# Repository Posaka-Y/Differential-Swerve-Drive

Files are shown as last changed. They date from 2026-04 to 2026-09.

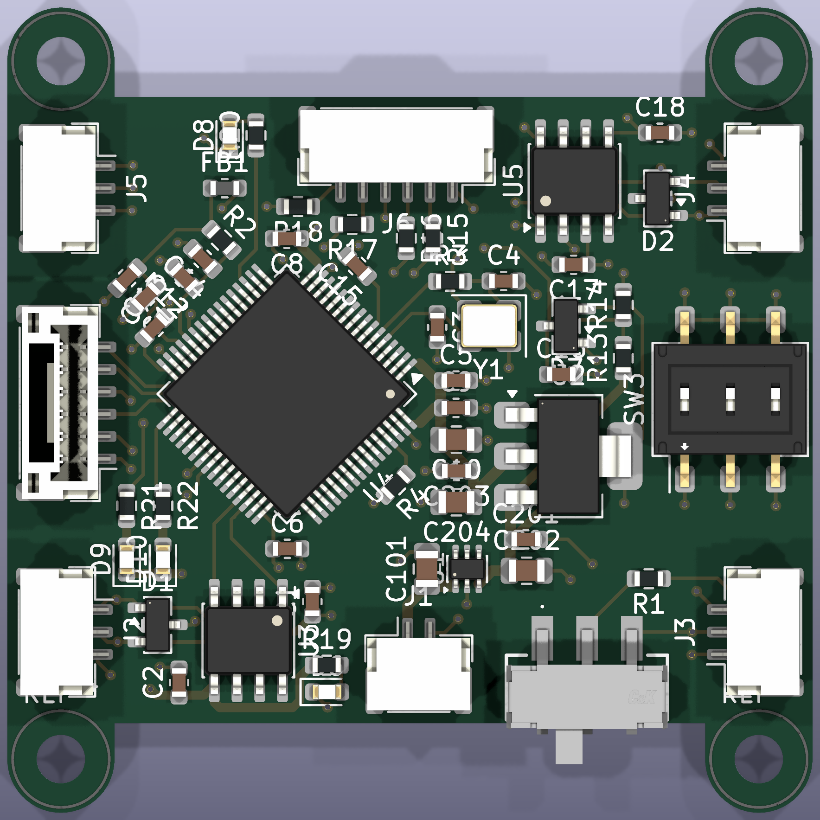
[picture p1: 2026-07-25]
.ai_board_top.png

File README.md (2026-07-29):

# Differential Swerve Drive

差動ステアユニット3基で構成する移動機構の、機構・制御・基板・ファームウェアをまとめた開発リポジトリです。

各ユニットはM3508+C620を2組とAMT222A-Vを持ち、ユニット内で差動の操舵・駆動制御を完結します。中央Teensy 4.1が3ユニットを協調制御し、mini PCはUSB-CDC経由でGUI・ログ・キャリブレーション操作を担います。

## 現在の構成

```text
mini PC (GUI / log)
  | USB-CDC
Teensy 4.1 (中央制御・安全I/O)
  |-- CAN1: 差動ステアユニット x3
  |     `-- STM32G474RET6 + C620 x2 + M3508 x2 + AMT222A-V
  |
  `-- CAN3: オドメトリ/IMUノード (unitId=4)
        `-- STM32F405RGT6 + AMT102 x3 + ICM-42688-P
```

- 中央CANとユニット内C620 CANは、いずれもClassic CAN 1 Mbpsの別バス。
- 制御系は中央の24V→5V降圧から`COMM_A / COMM_B / +5V / GND`で分配し、各基板で3.3Vを生成する。
- 確定事項の唯一の正本は[docs/ARCHITECTURE_DECISIONS.md](docs/ARCHITECTURE_DECISIONS.md)。

## まず読むもの

| 目的 | 文書 |
|---|---|
| 文書全体の案内 | [docs/PROJECT_DOCUMENT_INDEX.md](docs/PROJECT_DOCUMENT_INDEX.md) |
| 現在地・次の作業 | [PROGRESS.md](PROGRESS.md) |
| 設計上の確定事項 | [docs/ARCHITECTURE_DECISIONS.md](docs/ARCHITECTURE_DECISIONS.md) |
| 全体構成と責務 | [docs/SYSTEM_ARCHITECTURE.md](docs/SYSTEM_ARCHITECTURE.md) |
| ユニット基板・中央基板・オドメトリ基板 | [docs/electrical/](docs/electrical/) |
| 制御・運動学 | [docs/control/](docs/control/) |
| CAN・ネット名・メッセージ | [docs/communication/COMMUNICATION_NAMING_AND_IDS.md](docs/communication/COMMUNICATION_NAMING_AND_IDS.md) |
| ファームウェア | [firmware/README.md](firmware/README.md) と [firmware/PROGRESS.md](firmware/PROGRESS.md) |
| KiCad基板設計 | [hardware/README.md](hardware/README.md) |

階層化済みの`docs/control/`、`docs/electrical/`、`docs/communication/`などが更新対象です。`docs/`直下の旧メモは履歴として保存しており、更新対象ではありません。

## よく使うコマンド

リポジトリルートで実行します。

```powershell
# STM32G474 ファームウェア
.\firmware\scripts\build.ps1
.\firmware\scripts\flash.ps1

# KiCad設計のERC・PDF・DRC確認
.\tools\kicad\check.ps1
```

ファームウェア用ツールチェーンはスクリプトが自動検出します。パスに日本語を含むため、ビルド系スクリプトでは絶対パスを`cmd.exe`経由で渡さず、相対パスを使います。

## リポジトリ構成

```text
docs/       設計仕様、設計判断、試験計画
firmware/   STM32G474向けファームウェアとベンチ検証記録
hardware/   KiCadプロジェクト、共通ライブラリ、参照回路
tools/      KiCad検証などの補助スクリプト
```

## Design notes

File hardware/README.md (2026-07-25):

# hardware

KiCadによる基板設計。共通ブロック方針は `docs/electrical/CARRIER_BOARD_BUILD_PLAN.md` 冒頭を参照。

## 構成

```text
hardware/
  lib/             共通シンボル・フットプリントライブラリ
  blocks/          共通階層シート(can_interface, power_input_5v, status_led, mcu_min_g474)
  unit-board/      差動ステアユニット基板(STM32G474RET6)
  central-board/   中央制御ボード(Teensy 4.1)
  odometry-board/  オドメトリ基板(STM32F405RGT6 + AMT102 A/B相 x3)
  reference/       流用元プロジェクト(下表)
```

## 流用元(reference/)

| 参照 | 形式 | 流用するブロック | ライセンス |
|---|---|---|---|
| `candleLightFD/` ([linux-automation/candleLightFD](https://github.com/linux-automation/candleLightFD)) | **KiCadソース**(階層シート: MCU / PSU / transceiver) | CANトランシーバ周り(TJA1051T/3 + 100nF + 120Ω)→ `TCAN1051VDRQ1`に置換して `blocks/can_interface` の下敷きにする。階層シートの切り方・リリースフォルダ構成(製造データの出し方)も運用の手本になる | CERN-OHL v1.2(流用時はライセンス表記を維持) |
| `mks-canable-v2.0-schematic.pdf` ([makerbase-mks/CANable-MKS](https://github.com/makerbase-mks/CANable-MKS)) | PDF回路図 | STM32G431のMCU最小構成(電源、BOOT0、水晶、SWD)。G474RET6版を起こすときの照合用 | 回路図公開(リポジトリ記載に従う) |
| `nucleo-g474re-mb1367-c05-schematic.pdf`(ST MB1367)**※未取得** | PDF回路図 | **G474RET6そのものの最小構成の正解例**(VDD/VDDA処理、NRST、BOOT0、HSE周り)。ピンごとのデカップリング数の確認はこれを正とする | ST評価ボード回路図(参照用) |
| `ARK_CANNODE/` ([ARK-Electronics/ARK_CANNODE](https://github.com/ARK-Electronics/ARK_CANNODE)) | PDF回路図 + BOM(`Hardware/Rev 1/`) | 逆接保護(LM66100)、CANコネクタ2個並列のデイジーチェーン渡り、外部信号のESDダイオード、TJA1051+FET切替終端(参考のみ)。詳細は`CARRIER_BOARD_REQUIREMENTS.md`「回路図作成メモ」 | リポジトリのLICENSE参照 |
| `datasheets/` | データシートPDF | AMT22 rev1.10(コネクタピン順1=+5V/2=SCLK/3=MOSI/4=GND/5=MISO/6=CS)、PESD1CAN rev04(1/2=ライン、3=GND) | メーカー資料(参照用) |

※ MB1367回路図はst.comが自動取得を弾くため手動ダウンロードが必要:
<https://www.st.com/resource/en/schematic_pack/mb1367-g474re-c05_schematic.pdf>(または c04)。取得したらこのフォルダに上記ファイル名で保存する。

## 設計ルール

- 回路図のネット名は `docs/communication/COMMUNICATION_NAMING_AND_IDS.md` の命名に従う(`COMM_A/B`、`C620_CAN_*`、`PWR_*`、`_N`)。
- ピン割当は `docs/electrical/CARRIER_BOARD_REQUIREMENTS.md`(ユニット)/ `ODOMETRY_BOARD_REQUIREMENTS.md`(オドメトリ)の表が正本。
- シンボル・フットプリントは`lib/`に置き、KiCad標準ライブラリ依存を減らす(後続プロジェクトへの持ち出しやすさ優先)。
- プロジェクト固有ライブラリの収録範囲と標準ライブラリ割当は`lib/LIBRARY_MANIFEST.md`を正本とする。標準部品を無理由に複製しない。
- 発注前チェックは `docs/checklists/REVIEW_CHECKLIST.md`。

## CLI検証

KiCad 10で保存した回路図・PCBは、リポジトリルートから次で検証する。

```powershell
.\tools\kicad\check.ps1
```

既定では `hardware/unit-board/unit-board` を対象にERC、回路図PDF出力、DRCを実行し、結果を
`$env:TEMP\differential-swerve-kicad-check` へ保存する。CI相当の厳格な確認では
`-FailOnViolations`を付け、ERC/DRC違反があれば終了コードを非0にする。

PCB未着手の段階で回路図だけを厳格確認する場合は、空PCBのDRCを省く。

```powershell
.\tools\kicad\check.ps1 -FailOnViolations -SkipDrc
```

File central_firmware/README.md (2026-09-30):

# Teensy central-control firmware

`central_firmware`はTeensy 4.1中央制御のハードウェア非依存コアから実装を始める。
現段階ではCAN/USB/安全I/Oドライバを含まず、`control/swerve_coordinator`と
`control/steer_trajectory`が次を担当する。

- 車体twistとtwist微分から3ユニットのsteer角、wheel rpm、FFを同一時刻断面で算出
- 低速時だけの中央flip判断と連続unwrap角
- 停止特異点で直前steer角を保持
- 3ユニットの最悪要求に合わせたplanned motor-rpm包絡の共通scale
- 新指令後のSTATUS3 Low→Highを要求する3輪`MOTION_SETTLED`集約
- rate/accel/decel/jerk制約とjerk過渡込み停止距離を持つunwrapped steer軌道

駆動ユニットは半径0.250mの円上へ120deg等配する。車体`+X前・+Y左`でunit 1/3間の辺を
`+Y`側(センサーモジュール搭載側)に置き、unit 1=`(-216.5,+125)mm`、
unit 2=`(0,-250)mm`、unit 3=`(+216.5,+125)mm`とする。
公称車輪径は65mmなので、`default_coordinator_config()`は半径0.0325mと上記座標を設定する。
接地変形や製造差を実走距離から校正した場合は、各`wheel_radius_m`を実効半径で上書きできる。
半径が0以下のユニットを含む設定は指令生成を拒否し、全出力を0に保つ。

ホスト試験:

```bash
central_firmware/scripts/test-host.sh
```

次段階は、正本の機体寸法を設定したうえでTeensy 4.1のFlexCAN_T4アダプタ、200Hz
twist/steer profiler、通常STOP/ESTOP状態機械をこのコアの外側へ接続する。空走P4では
jerk=100k/200kを評価したが応答優先ではjerk=0が最速だったため、production configの
non-zero jerk採用値は接地3輪試験後に確定する。

## 再アーム判定コア（2026-09-26）

control/arm_controllerを追加。GUI ARMイベントとSW211押下を同じ安全判定へ入力し、ARMによるコイル許可とRUNによる運転許可を分離する。詳細はdocs/software/MINIPC_GUI_AND_TEENSY.md。

アダプタは毎周期ArmInputsを構築する。初期値は安全側（未許可）。GPIOにmotor_power_enableを反映し、motion_permitted=falseでは車輪出力をゼロにする。boot_sessionは起動/GUI再接続ごとに新しい値を供給し、再接続時はコントローラを再初期化する。USB受信イベントをキューへ保持せず、期限切れリンク/指令をlinks_ok=falseへ反映する。run_eventはC620立上がりや運転の他条件を確認したイベントだけを渡す。

これは判定コアの実装であり、Teensy GPIO/USB、本体ディスプレーGUIとの接続は未実装。今回ビルド・テスト・書き込みは実施していない。

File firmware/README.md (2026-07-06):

# NUCLEO-G474RE firmware

STM32G474RET6 向けの GCC/CMake ベアメタルプロジェクトです。NUCLEO-G474RE の B1 USER (PC13、アクティブHigh) を押している間、LD2 (PA5) が点灯します。入力は20 msデバウンスされます。

## 必要なツール

- STM32Cube for Visual Studio Code 拡張
- Arm GNU Toolchain (`arm-none-eabi-gcc`) — `winget install Arm.GnuArmEmbeddedToolchain`
- CMake 3.22 以降
- Ninja
- 書き込み時のみ STM32CubeProgrammer

CMake / Ninja / STM32CubeProgrammer / ST-LINK GDB Server は STM32Cube 拡張が
`%LOCALAPPDATA%\stm32cube\bundles` に導入済みのものを使う。手動で PATH に
追加する必要はない。`scripts/toolchain.ps1` が build/flash 実行時に自動で
発見して PATH へ載せる(優先順: 既存 PATH → 拡張バンドル → Arm GNU Toolchain
既定インストール先)。

VS Code のデバッグ構成 (`.vscode/launch.json`) はバンドル内の
`arm-none-eabi-gdb` / `ST-LINK_gdbserver` / `STM32_Programmer_CLI` を
絶対パスで参照している。拡張がバンドルを更新してバージョンディレクトリが
変わった場合はパスを追従させること。

## CLI

リポジトリのルートから実行します。

```powershell
.\firmware\scripts\build.ps1
.\firmware\scripts\build.ps1 -Configuration Release
.\firmware\scripts\flash.ps1
```

POSIX 環境では `firmware/scripts/build.sh` と `flash.sh` を使えます。生成物は `firmware/build/debug` または `firmware/build/release` に配置されます。

## 構成

- `src/main.c`: アプリケーションのエントリポイント
- `src/platform/`: STM32 固有の startup、clock、GPIO
- `include/app_config.h`: アプリ共通設定
- `linker/`: メモリマップ
- `cmake/`: GCC クロスコンパイル設定
- `scripts/`: 再現可能なビルド・書き込みコマンド

新機能は原則として `src/` と `include/` の対応するモジュールへ追加し、MCU レジスタへの直接アクセスは `platform/` 内に限定します。

自作基板へ移行するときは、最初に `src/platform/gpio.c` のLED・ボタンのポート、ピン番号、入力極性を基板回路に合わせて変更します。

実機書き込みで詰まりやすい点、接続モード、エンコーダの配線・段階テスト、自作基板のSWD要件は [docs/BOARD_BRINGUP.md](docs/BOARD_BRINGUP.md) にまとめています。

現在の完了項目、実機状態、次の作業は [PROGRESS.md](PROGRESS.md) を参照してください。

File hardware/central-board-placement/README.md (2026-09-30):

> **作業先訂正 2026-09-29:** 現行は `hardware/central-board/central-board/central-board.kicad_pro`。22:45保存版へ移行済みで、クランプD405も `safety-1.kicad_sch` に反映済み。ERC0件。下記のcentral-board-placement対象/既存CAN4件という記載は以前の作業履歴。

> **2026-09-29クランプ更新:** X401→D405 AOS SMBJ33CA、SMB footprint割当済み。コイル両端並列、未割当9件。ERCは既存CAN4件。サージ/解放時間の実測・X402帰路結合は残件。

> **最新 2026-09-29：電源・CAN以外の配線を反映。** S02B/S04/S05、GPIO4pin×4組、Teensy用途ラベル。ERC193→4（残りCAN電源4件）。S04のヒューズ/クランプ/帰路結合/正式コネクタはTBD。157参照番号。以下の旧未配線・部品数記載は履歴。詳細は [配線記録](../../docs/electrical/CENTRAL_NONPOWER_WIRING_2026-09-29.md)。開いているKiCadは古い画面を保存せず再読込。

> **E-stop 2026-09-26更新:** U401 LTV-817S 1ch、J401は4pin（型番未確定）。ボタン別/予備監視16部品を削除。現在158実部品。前回ERCは変更前の記録。

# 中央基板 — 階層回路図・部品配置からの設計開始

> **2026-09-29更新:** J210の使用端子40本は用途global label、予約8本はNCで区別。新規global label30個、再アーム誤記READ_SW_N→REARM_SW_Nを訂正。C212/GNDだけ表示干渉を避けて移動し、同名3V3で接続。全48padのネット対応と既存ネット分断なしを検証。ERC217→194件（未配線等が残る）。最新人間向けPDFは`output/pdf/CENTRAL_BOARD_REV1_SCHEMATIC_2026-09-29.pdf`。KiCadで開いている場合は再読込してから編集を続ける。

> **2026-09-26現在: ユーザーがS02A電源回路の手配線を開始。** 以下の未配線/部品数/ERC一覧は初期配置時点の履歴。生成器で原本を再生成しない。電源回路は修正・再確認済み。最新記録は`output/kicad-check/central-power-fix-2026-09-26/REVIEW.md`を参照。現在174実部品、電源シートERC0件、全体383件。既にエディタで開いている場合は古い画面を保存せず再読込すること。

2026-09-23のユーザー指定に基づく、手配線用の新規プロジェクト。
トップシートを目次とし、機能別の子シートへシンボルを配置する。
**電源回路は配線・修正済み。他回路は未配線。製造用の完成回路図ではない。**

## 開き方

このフォルダの `central-board-placement.kicad_pro` をKiCadで開き、回路図エディタから
トップシート内の各階層シートを開く。
以後の手編集はこの新規プロジェクトで行う。
既存の `../central-board/central-board/` は別の作業データであり、今回置換しない。

トップ＋7子シート、178部品（LTV-847Sの4ユニットを含め181シンボル）。

| 子シート | 用紙 | 部品数 |
|---|---|---:|
| 5V入力・eFuse・USB diode-OR | A2 | 32 |
| 5V分配・Teensy・表示 | A2 | 38 |
| CAN1 センサ | A3 | 10 |
| CAN2 拡張 | A3 | 11 |
| CAN3 駆動 | A3 | 10 |
| E-stop監視・中央コイルdriver | A2 | 33 |
| Matek監視端子・外部I/O | A2 | 44 |

## 作業の境界

- 部品配置のみ。配線、ネットラベル、階層信号ピン、電源シンボル、NC指定は未作成。
- RefDesと部品値を付け、機能ごとの配線用余白を設ける。
- 未確定の部品値・型番・footprintはTBD/REVIEW等で明示する。
- 多ユニット部品は同一RefDesの各unitとして配置する。
- 未接続に関するERC結果はこの段階では意図された状態。ERC合格や製造可能とは扱わない。
- PCB配置・配線は含まない。

## 仕様参照

優先する資料:

1. `docs/ARCHITECTURE_DECISIONS.md`
2. `docs/electrical/PCB_BATCH_V2_CENTRAL_PLAN.md`
3. `docs/electrical/CENTRAL_BOARD_REV1_PDF_CHANGELOG_2026-09-23.md`
4. `docs/electrical/CENTRAL_BOARD_REV1_KICAD_ENTRY_REFERENCE.md`

2026-09-23版のCAN端子・中央コイルdriver・Teensy一体ソケットを基準とし、
旧資料の別体driver、基板内Buck、主接点専用監視回路を復活させない。
専用CANはGH3、汎用拡張CANだけは既存GH4の区別を保つ。
未確定箇所は接続・footprint・購入型番を確定してからPCBへ進める。

### 旧資料を参照するときの注意

- `reference-2026-09-12/modules-native/POWER_A_B1.kicad_sch` の旧eFuseシンボルは
  TPS259470LRPWRのpin番号が正本と異なるため流用しない。
  正番号はEN/UVLO=1、OVLO=2、AUXOFF=3、FLT=4、IN=5、OUT=6、
  dVdt=7、GND=8、ILM=9、ITIMER=10。
- Teensyのpad4は`MOTOR_PWR_EN`に使用する。旧転記表末尾のNC列挙より
  正式な48pin対応表を優先する。配置時点ではNCシンボル自体を置かない。
- Teensyの一体48pad footprintは2個の24pinシンボルへ重複して割り当てない。

## 再生成について

`tools/kicad/generate-central-placement.py` と部品一覧JSONは初期配置の生成元。
**手配線を始めた後は再生成で上書きしないこと。**
必要な変更はKiCad上で行うか、別出力先へ生成して比較する。

## 初期配置の確認結果

### 2026-09-26仕様差分の反映

- Teensy J210の右列表示順を48→25へ訂正（左列1→24、USB側を上）。ライブラリと回路図内cache、生成器を同期。全48pinの番号/信号名対応とソケットfootprintは保持。USB END表示を追加。PDFのTeensy図は元からこの順序。

- 同日追加指定で駆動Unit 1〜3の給電枝TP211〜TP213を削除。LEDで給電状態を見て、必要時はJ201〜J203で電圧を実測する。最新ERCは未接続493/入力未駆動13/電源未駆動15。

- USB側U102 `TPS259470ARPWR`、R107〜R112、C106〜C108、TP106を追加。外部5V優先のOVLO分圧、約1A制限、既存D102保持経路は転記表3.1に従う。
- GPIO電源列選択JP505を追加。1=3V3、2=VCC_GPIO_EXT（J507-1）、3=5V_EXP。ショートピン1個、出荷時1-2。IO/TVSは3.3Vのまま。
- J210のpad11/pin9はUSB fault入力候補と注記（提案）。pad36はNC。接続は手配線時に作成する。
- 既存全素子の座標/向き/UUIDを保持し、電源シートをA2へ拡張して下側へ追加した。元ファイルは`output/kicad-check/central-placement-2026-09-26/before/`へ退避。
- U101 `TPS259470LRPWR` / U102 `TPS259470ARPWR` のRPW footprintは未割当。ユーザーがPart Loaderで取得予定。JP505はKiCad標準1x3ヘッダfootprintを使用し、購入型番は未確定。
- 手配線用回路図: `output/pdf/CENTRAL_BOARD_REV1_SCHEMATIC_2026-09-26.pdf`（15ページ、14=USB eFuse、15=GPIO電源選択）。9月23日版は履歴として保持。
- ERCは未接続496、入力未駆動13、電源未駆動15のみ。配線前の状態であり製造用のERC合格ではない。

以下は2026-09-23初期配置時点の結果。最新版の検査は上記9月26日記録を参照。

KiCad 10のSVG/netlist出力成功。部品一覧との全件照合、Ref/unit重複なし、
主要ICのpin番号、割当footprintの実在、配線/ラベル/NCなしを検査した。
8ページを画像化して重なり・ページ外はみ出しを目視確認済み。
ERCは意図的な未接続464件・未駆動24件で、off-grid/library mismatchはない。
検査記録は `output/kicad-check/central-placement/`。

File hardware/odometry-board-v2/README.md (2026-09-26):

# V2 作業用プロジェクト

2026-09-23着手。**設計途中・製造禁止**。

要件正本: [UNIT_ODOMETRY_V2_REQUIREMENTS.md](../../docs/electrical/UNIT_ODOMETRY_V2_REQUIREMENTS.md)

V1の保存済み作業ツリーから分離した。ファイル名を維持しているのはKiCad階層インスタンス参照のため。
V1の製造済み基板との差分は基準マニフェストを参照。

2026-09-23: 回路図の旧GH6デバッグ端子J8を駆動V2と同じCortex Debug 1.27mm 2×5配列へ変更。1=MCUデジタル3.3VのVTref、2=SWDIO、3/5/9=GND、4=SWCLK、6=SWO、7/8=NC、10=NRST。UARTは独立した2.54mm 1×3スルーホールヘッダJ9（1=GND、2=MCU TX、3=MCU RX）へ変更。3.3Vロジック専用で給電ピンはない。ERC 0、変更箇所以外のネット接続比較を確認済み。詳細は`../../output/kicad-check/v2/odometry/swd-10pin-check.md`と`uart-header-check.md`。

J8の正式MPN・嵌合ケーブル・フットプリントは未確定で、回路図のFootprintは意図的に空欄。V2 PCBは旧GH6のまま、UART J9も未反映で、回路図との同期前に製造してはいけない。

ODOMのU3/U7/U9電源unit Cだけ回路図へ反映済み。ERC 0、XML netlistで6電源pinを確認。PCBの当該6padは未更新なので、回路図からPCBを更新し、電源配線と100nFを確認すること。

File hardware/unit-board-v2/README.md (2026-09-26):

# V2 作業用プロジェクト

2026-09-23着手。**設計途中・製造禁止**。

要件正本: [UNIT_ODOMETRY_V2_REQUIREMENTS.md](../../docs/electrical/UNIT_ODOMETRY_V2_REQUIREMENTS.md)

V1の保存済み作業ツリーから分離した。ファイル名を維持しているのはKiCad階層インスタンス参照のため。
V1の製造済み基板との差分は基準マニフェストを参照。

2026-09-23: 駆動回路図の旧GH6デバッグ端子J7をCortex Debug 1.27mm 2×5配列へ置換。pin1=MCUデジタル3.3V(VTref)、2=SWDIO、3/5/9=GND、4=SWCLK、6=SWO、7/8=NC、10=NRST。UARTは独立した2.54mm 1×3スルーホールヘッダJ9（1=GND、2=MCU TX、3=MCU RX）へ変更。3.3Vロジック専用で給電ピンはない。ERC 0、既存接続照合を確認済み。レポートは`../../output/kicad-check/v2/unit/uart-header-check.md`。

J7の正式MPN・キー形状・嵌合ケーブル・フットプリントは未確定で、回路図のFootprintは意図的に空欄。PCBはV1の旧GH6配置・配線が残るため、回路図との同期前に製造してはいけない。UART J9もPCBへ未反映。

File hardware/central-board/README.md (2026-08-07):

# Central board schematic

## Files

- `central-board.sch`: 責務別child sheetを並べたroot index。
- `modules/100-power.sch`: 5V入力、eFuse、star distribution。
- `modules/200-teensy.sch`: Teensy 4.1 socket、固定pin map、安全出力のdefault state。
- `modules/300-can.sch`: Sensor / Expansion / DriveのCAN 3系統。
- `modules/600-safety.sch`: 24V E-stop loop、contactor driver、絶縁監視、motor bus sense。
- `modules/700-monitoring.sch`: INA238と外付けKelvin shunt interface。
- `modules/800-expansion.sch`: I2C/UART/SPI/GPIO、rearm、test access。
- `../../tools/kicad/generate-central-board-modules.ps1`: root＋6 moduleの再生成script。
- `../../tools/kicad/generate-central-board-schematic.ps1`: module生成の入力になる詳細回路generator。通常は直接実行しない。
- `../../docs/electrical/CENTRAL_BOARD_SCHEMATIC_WITH_BOM.html`: オドメトリ／駆動module資料と同じA3横テンプレートのreview正本。
- `../../output/pdf/CENTRAL_BOARD_SCHEMATIC_WITH_BOM.pdf`: 1機能1ページの回路図＋注意点＋簡易BOM、全7ページ。

## 開き方

KiCad Schematic Editorから`central-board.sch`を直接開き、rootのsheet blockから担当moduleへ移動する。初回保存時にKiCadの現行`.kicad_sch`形式へ変換してよい。変換後は生成scriptによる上書きを止め、`.kicad_sch`と変換されたchild sheetsを正本へ切り替える。

## 現段階の使い方

人間reviewでは`CENTRAL_BOARD_SCHEMATIC_WITH_BOM.pdf`を先に使い、1機能ずつ信号の流れ、注意点、BOMを確認する。KiCad sheetはその結果を転記してERCするための下位資料であり、review PDFの代用にはしない。TPS259470、TCAN1051、INA238、LTV-847Sなどの正式pinはdatasheetとKiCad symbolの両方で最終照合する。

PCBへ進む前に次を行う。

1. generic symbolを正式なlibrary symbolへ置換し、pin typeとfootprintをdatasheetに対して照合する。
2. 図中`TBD`をすべて閉じる。特にeFuse UVLO/OVLO、24V input保護、contactor clamp、shunt sense source fuse。
3. `docs/electrical/CENTRAL_BOARD_SCHEMATIC_REFERENCE.md`の接続表とcross-checkする。
4. No Connect、PWR_FLAG、power pin typeを整理し、ERC 0件へ収束させる。

現時点のKiCad ERCはgeneric pin-explicit symbolとlegacy `.sch` labelのためacceptance判定に使用しない。PDF/netlist出力が可能なことまでは確認済みで、PCB開始条件は`.kicad_sch`化後のERC 0件である。

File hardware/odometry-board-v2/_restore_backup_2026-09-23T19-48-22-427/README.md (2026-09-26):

# V2 作業用プロジェクト

2026-09-23着手。**設計途中・製造禁止**。

要件正本: [UNIT_ODOMETRY_V2_REQUIREMENTS.md](../../docs/electrical/UNIT_ODOMETRY_V2_REQUIREMENTS.md)

V1の保存済み作業ツリーから分離した。ファイル名を維持しているのはKiCad階層インスタンス参照のため。
V1の製造済み基板との差分は基準マニフェストを参照。

2026-09-23: 回路図の旧GH6デバッグ端子J8を駆動V2と同じCortex Debug 1.27mm 2×5配列へ変更。1=MCUデジタル3.3VのVTref、2=SWDIO、3/5/9=GND、4=SWCLK、6=SWO、7/8=NC、10=NRST。UARTは独立した1.5mm padのTP901(TX)、TP902(RX)、TP903(GND)。ERC 0、変更箇所以外のネット接続比較を確認済み。詳細は`../../output/kicad-check/v2/odometry/swd-10pin-check.md`。

J8の正式MPN・嵌合ケーブル・フットプリントは未確定で、回路図のFootprintは意図的に空欄。V2 PCBは旧GH6のままで、回路図との同期前に製造してはいけない。

ODOMのU3/U7/U9電源unit Cだけ回路図へ反映済み。ERC 0、XML netlistで6電源pinを確認。PCBの当該6padは未更新なので、回路図からPCBを更新し、電源配線と100nFを確認すること。

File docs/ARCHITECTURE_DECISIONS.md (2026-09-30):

# アーキテクチャ決定事項

## 確定事項

| 論点 | 決定 |
|---|---|
| 中央安全回路の帰路結合 X402 | **2026-09-30:** `GND_CTRL`、`GND_CTRL_LED`、`GND_24V_RETURN`を中央基板上の1箇所で結ぶ。X402は購入部品ではなく3端子銅箔ネットタイとし、KiCad標準`NetTie:NetTie-3_SMD_Pad2.0mm`を採用。PCBではJ403-2とQ401 sourceの近傍に置き、コイル/LED帰路を制御GNDプレーン経由で流さない。外部24V負極と5V/USB側GNDの別経路結合の有無、PCB帰路、DRCは実装前に確認する。 |
| 中央コイルクランプの型番 | **2026-09-29ユーザー承認:** SMBJ33CA双方向TVSを採用。直前に参照したAOS品でメーカーを固定し、D405（旧X401）、Device:D_TVS、Diode_SMD:D_SMBとしてJ402コイル両端へ並列接続。メーカー資料とランド寸法を照合。実装ハーネスでのサージ/パルス耐量/解放10ms以内の検証は残件、X402帰路結合は別途未確定。 |
| TN686コイルの現物確認 | **2026-09-29ユーザー確認:** TN686・24V・100A表記、コイル抵抗実測340Ω、内部保護なし。24V時約70.6mA/1.69Wは計算値として使用。解放10ms未満は提示販売仕様であり、クランプ追加後の実測保証ではない。旧300Ωや混載ページの2.4W/4.8Wと区別する。 |
| メインコンタクタ現物表記の追加確認 | **2026-09-29ユーザー回答:** `TN686`。旧E228記録との対応、1.8W/300Ωの適用は未照合。TN686の末尾型式・コイル定格・保護素子有無を確認するまで、旧数値でクランプ/ヒューズを確定しない。現物再利用方針そのものを変更する指示ではない。 |
| 中央回路の配線担当・GPIO4ポート反映 | **2026-09-29ユーザー指定:** 電源・CAN以外はAIがKiCad回路配線を行う。9/23のユーザー手配線方針をこの範囲で更新。S02B/S04/S05へ反映し、GPIOは4pin×4組(J507〜J510、既存SM04B-GHS-TB共通)、JP505全組共通電源選択。電源/CANシートは維持。安全回路の保護部品/帰路結合はTBDのままで、製造確定ではない。 |
| E-stop LEDの実測消費電力 | **2026-09-29ユーザー追加測定:** X1-X2のLED負荷は24Vで約0.3W（約12.5mA）。1個測定なら2個合計は約25mA/0.6W。先の20V/0.2Wからの比例推定ではなく、この実測を枝保護選定の入力にする。測定個数は明示未確認、保護部品定格自体は未確定。 |
| 中央未確定部品の選定方針 | **2026-09-29ユーザー指定:** 未確定のコンデンサ・タクト・コネクタは既存基板との共通化を優先。正式採用は定格・メーカー図面照合後に記録する。 |
| E-stop現物端子の使用方針 | **2026-09-29ユーザー申告・方針:** PMD22-03-24R、端子は11-12/21-22/31-32/X1-X2。X1-X2に24Vを加えて押下時LED点灯を現物確認済み。安全ループは各ボタンの11-12を使用する方針、他接点は今回不使用。11-12の解除時導通/押下時開放、LED極性は最終配線時に照合。20V・0.2Wの測定申告は10mA相当（測定個数・24V時電流は未確認）。J401は現行4pinを維持、2pin化は未確定。 |
| 中央GUI・物理ボタン共通ARM | **2026-09-26ユーザー確定:** 本体ディスプレーGUIのARM要求とSW211の新規押下をTeensyの共通再アーム判定へ入力する。E-stop解除だけでは復帰しない。ループ成立・GUI/駆動3基/ODOM通信正常・他異常なし・動作指令ゼロで新規操作だけを受理。停止前/再起動前/再接続前の要求は持ち越さず、ARM後も別の新しい運転要求まで動作指令を遮断。SW211は整備用タクトスイッチのまま維持。 |
| 中央E-stop監視1ch化 | **2026-09-26ユーザー確定: 直列NCループ全体のみをU401 LTV-817Sの1chで監視する。** ボタン個別補助接点の監視と予備chは削除。J401はループ往復＋独立保護24V LED電源/帰路の4pin（正式コネクタ未確定）。コンタクタはJ402 COIL_POS/COIL_NEGの2線。ハードNC遮断・reset/Hi-Z OFF・明示再アームを維持。旧6pin/4ch仕様より本決定を優先。 |
| 中央基板 駆動枝テストポイント省略 | **2026-09-26ユーザー確定: 駆動Unit 1〜3の給電枝TP211〜TP213を省略する。** D201〜D203の枝LEDで給電状態を見て、電圧実測はJ201〜J203の電源/GND接点で行う。LED点灯は電圧値やノード正常を保証しない。ODOM/Teensy/ExpansionのTP214〜TP216と主電源/CAN等のTPは今回の省略対象外。 |
| 中央基板 GPIO電源の3.3V/5V切替 | **2026-09-26ユーザー確定: GPIOコネクタの電源ピンだけを、列全体でジャンパ1個(JP505、2.54mm 1x3ヘッダ+ショートピン)により`+3V3_TEENSY`/`+5V_EXP`から選ぶ。** ピンごとの切替はスペースのため行わない。IO信号はTeensy 4.1が5V非対応のため3.3Vのまま(レベル変換なし、ADC維持)。出荷時は3.3V。I2C/SPIの電源ピンは3.3V固定 |
| 中央基板 USB単独給電の範囲 | **2026-09-26ユーザー要望で拡張: USBだけでCAN試験とノード1基分の5V給電ができるようにする。** Teensy VUSB→第2 eFuse `U102 TPS259470ARPWR`（auto-retry、`RILM=3.32kΩ`でILIM 0.85/1.007/1.15A）→`+5V_SYS`へ給電し、トランシーバ3個と枝PPTCもUSBで動かす。外部5V優先は`+5V_RAW`分圧（100k/37.4k）をU102 OVLOへ入れ、外部5V≥4.41Vで出力OFFにして実現する。両eFuseのtrue RCBでUSB⇔外部5Vの逆流なし。D102（VUSB→VIN直結diode）は切替時・U102過電流時のTeensy保持用に残す。USB単独時はUSB3ポートかセルフパワーハブを推奨し、2基以上つなぐとU102が電流制限する。詳細は`electrical/CENTRAL_BOARD_REV1_KICAD_ENTRY_REFERENCE.md` 3.1節 |
| 駆動V2 C620 CAN終端配置 | **2026-09-26ユーザー確定: 基板の2個のGHポートからそれぞれESCへ接続し、各ESCの120Ω終端をONとする。** ESC①（120Ω）―駆動基板（終端なし）―ESC②（120Ω）の一本のバスとして扱う。駆動基板内にC620用終端抵抗は追加しない。中央CAN終端とは独立。 |
| 駆動V2 AMT22変換ハーネス | **2026-09-26ユーザー確認: J6はケーブルに合わせた1=CS、2=MISO、3=GND、4=MOSI、5=SCLK、6=+5Vで確定。** センサ側1=5V/2=SCLK/3=MOSI/4=GND/5=MISO/6=CSに対し、基板J6→センサは1→6、2→5、3→4、4→3、5→2、6→1。旧ストレート結線記述はV2に適用しない。 |
| 駆動V2 5V監視分圧 | **2026-09-26ユーザー確認: R13=33kΩ（5V側）、R14=22kΩ（GND側）を採用し33kΩを調達する。** 分圧比0.4、5V入力時ADC2.0V。V2ファーム換算はVin=ADC/4095×3.3/0.4。V1実装22kΩ/10kΩの0.3125設定は別管理し、今回ファームは変更しない。 |
| ODOM V2エンコーダ端子順 | **2026-09-25ユーザー確認: J4/J5/J6は1=A、2=+5V、3=B、4=GNDを採用する。** ハーネスのねじれを避けるための意図した変更。V2では旧1=5V/2=GND/3=A/4=B表より優先し、元へ戻す修正対象としない。 |
| 中央基板の回路図着手方法 | **2026-09-23指定: 機能別の階層回路図にシンボルを配置し、配線はユーザーが行う。** トップは目次、子シートは電源・Teensy・CAN・安全回路・外部I/O等に分割。配置作業は既存回路図と分けた新規プロジェクトで進め、未確定値/footprintを確定扱いにしない。 |
| V2共通UARTヘッダ | **2026-09-23追加確定: 駆動・ODOM V2のUART用TP3点を、2.54mmピッチ1×3スルーホール・ピンヘッダへ置換する。** 1=GND、2=MCU TX、3=MCU RX。3.3Vロジック、電源ピンなし。必要時のみヘッダ実装可。PCB配置・配線はユーザー担当。 |
| ODOM V2のSWD共通化 | **2026-09-23追加指定: ODOM V2のJ8も駆動V2 J7と同じCortex Debug 10pin配列へ変更する。** pin1=デジタル3.3V VTref、2=SWDIO、3/5/9=GND、4=SWCLK、6=SWO、7/8=NC、10=NRST。UARTは独立3pinヘッダへ分離（同日の追加指定）。正式ヘッダ/ケーブルの機構照合は別途行い、PCB更新はユーザーが担当する。 |
| 駆動V2インジケーター配置・作業分担 | **2026-09-23追加指定: PWR/RUN/COMM/ERRを一か所にまとめる。** PCB配置・配線はユーザーが担当し、AIは回路図修正・接続検査・設計資料更新を担当する。 |
| V1検証とV2改良の進め方 | **2026-09-23確定: V1実機で機能確認を継続し、並行してV2設計へ改善を反映する。** 実機個体/ファーム/ジャンパ/測定結果を記録し、設計不良と実装不良を区別する。V1の検証に必要なICは先に回収せず、回収は該当検証の完了・移行後に行う。V2回路図の検査合格と実機機能確認を混同しない。 |
| コンタクタ状態の補助診断 | **2026-09-23確定: コンタクタ主接点の専用監視は今回実装しない。** コンタクタ補助接点入力や主接点後24Vの専用電圧監視を追加せず、駆動MCUがC620のCAN応答有無を検出し中央へ報告する補助診断を用いる。制御5Vと中央↔駆動CANはOFF後も生かす。表示は「OFF指令中・C620応答なし」とし、CAN無応答を「遮断確認済み」や溶着検出の根拠にはしない。中央との通信自体が途絶した場合はC620応答なしと混同せず「通信不明/情報期限切れ」とする。ハードNC E-stopのコイル遮断、reset/Hi-Z時OFF、明示再アームを維持。ファーム/GUI実装は別作業。 |
| Teensy 4.1ソケット列間訂正 | **2026-09-23: ソケット列中心間は15.24mm、同列pitchは2.54mm。** 旧資料の「列間17.78mm」は基板幅との混同として訂正。基板外形60.96×17.78mmは維持。[PJRC公式寸法図](https://www.pjrc.com/teensy/dimensions_teensy41.png)で照合。既存PCBの離れた1x24ソケット配置は再利用せず、PCB作業時に整合を確認する。 |
| 次回PCB発注・部品予備 | **2026-09-23: 駆動V2・ODOM V2・中央基板の3種類をまとめて発注する方針。** 製造枚数は未確定。安価な共通部品は将来利用を含め多め、CAN TVSは実装必要数中心、高価なICは検査合格の回収品と在庫を優先する。具体数量案は`electrical/PCB_BATCH_V2_CENTRAL_PLAN.md`。現段階は設計資料作成で、購入・基板注文は未実施。 |
| 駆動/ODOM基板V2の優先方針 | **2026-09-23: V1の接続ミス是正とデバッグ性を機能追加より優先する。** 必須SWD信号はVTref/SWDIO/SWCLK/NRST/GND、両基板で規格を共通化し、UARTは独立3pinヘッダとする（同日の追加指定）。旧GH6デバッグ一体仕様はV1限定へ変更。キー・Pin1表示・測定TP・段階bring-up・電源pad全数監査を必須化。高価なICは検査後回収利用、安価な受動部品は新品と予備在庫を基本とする。Cortex Debug 1.27mm 2×5配列は同日ユーザー指定で確定し駆動V2のJ7に反映。正式MPN/ケーブルは未確定。詳細は`electrical/UNIT_ODOMETRY_V2_REQUIREMENTS.md` |
| LiPo x2 | 6S LiPo x2を並列運用する |
| E-stop | C620系の24V主電源を遮断し、制御系は生かす |
| E-stop個数・表示 | **非常停止ボタンを2個設け、両方のNC安全接点をコンタクタコイルループへ直列接続する(2026-07-19)。** 各ボタンの24V内蔵LEDはTeensyを介さず、E-stop後も生きる`24V_CTRL`からハードワイヤ給電する。点灯条件は操作パネル設計時に確定する |
| E-stop中央接続 | **中央基板に専用`ESTOP_CTRL`ポートを1個設ける(2026-07-25)。** 2個のE-stopを接続する操作パネル側ハーネスを1コネクタへ集約し、ハード直列NCループの往復、独立保護した24V LED電源/GND、LED帰路を収容する（2026-09-26: 個別補助接点入力は省略、4pinへ変更）。コネクタを抜くとNCループが開いてコンタクタが解放されるfail-safe構成とする |
| コンタクタ励磁 | **2026-09-23改版基本案: 次回中央基板へE228コイル励磁回路を統合する。** 9/17の別体CONTACTOR_DRIVER/スイッチング基板折り取り案は次回製造の前提から外す。中央Teensy MOTOR_PWR_ENからbuffer/ローサイドMOSFETを直接制御し、ハードNC E-stop直列遮断、reset/Hi-Z時OFF、明示再アームを維持。主接点のモータ大電流はPCB外。clamp/24V帰路/コネクタ詳細は回路図PDFで検討し、未確定項目を区別する。 |
| 遠隔モータ電源遮断 | **Teensyが`MOTOR_PWR_EN`を落としてコンタクタを解放する遠隔停止に対応する(2026-07-19)。** 停止はラッチし、明示的な再アームまで再励磁しない。mini PC/一般無線経由は補助停止として扱い、正式な安全無線E-stopが必要な場合は認証受信機の接点をNC安全ループへ追加する |
| メインコンタクタ | **所有品のKILIGEN `E228`(24V DC、100A表記)を採用する(2026-07-26)。主回路をMOSFET式solid-state遮断器へ置換せず、機械式コンタクタを継続する(2026-08-06再確認)。** コイル仕様(24V DC、1.8W、300Ω、動作14〜16V/解放6〜8V/最大印加28V DC、コイル電流約75〜80mA)は確認済みでコイルドライバ設計に使用可。正式なDC負荷遮断定格データシートは無いが、**この個体で前回ロボコン機体において約2000W(24V換算で約83A)の通電中にE-stop等で遮断できた実績を確認済み**(2026-07-26)。この実績値を正式定格の代替根拠として扱い、今回の想定最大電流が83Aを明確に超えないことを設計時に確認する。再利用前に主接点の摩耗・ピッティングを目視検査する。MOSFETはコイル駆動、precharge、回生brake chopperへ使用し、主遮断機能を担わせない |
| 機体状態LED | ミッション達成、状態、バッテリー残量を示すテープLED/表示LEDを追加する(2026-07-19)。安全表示は演出LEDから独立させ、LED方式・電圧・電力は部品選定時に確定する |
| LEDテープ制御 | **LEDテープは独立CANノード基板で制御する(2026-09-14更新)。** 中央TeensyからLEDのDATA線やピクセル列を直接配線せず、拡張CANでモード、色、明るさ、速度、状態などの高位コマンドを送る。LEDノードがアニメーションとピクセル波形をローカル生成し、CANへ毎フレームの全RGBデータを流さない。`STM32F303K8T6`+`TCAN1051VDRQ1`を採用し、12〜24V自己給電を`LMR51606XDDCR`+`TLV76133DCYR`で5V/3.3Vへ降圧する。24V WS2811互換テープはF303 timer+DMAと`SN74AHCT1G125`で作る5V 800kbps 1線信号にする（SPIではない）。中央とのハーネスは`COMM_A/B`の2線だけ。LED電力は中央PCBを通さず、24V分電点から専用ヒューズ経由で供給し、長尺/大電流テープは基板を経由せず現地注入する。詳細正本は`docs/electrical/LED_CAN_NODE_REQUIREMENTS.md` |
| GUI | mini PCで動かす |
| 手動コントローラ入力 | **Sony DualSenseはmini PCへBluetoothまたはUSBで接続し、mini PC→ESP32-C3をWi-Fi/UDP、ESP32-C3→TeensyをCAN2(Classic CAN 1Mbps)で中継する(2026-08-01、同日USB-CDC直結案から変更)。** ESP32は車体twist要求だけを`MANUAL_TWIST_CMD(0x080)`で渡し、3輪IK・軌道生成・Motor Enable最終判定はTeensyが担う。R1デッドマン解放、DualSense切断、UDP 150ms途絶時は0指令へ落とす。一般Wi-Fi/Bluetoothとこの0指令は正式なE-stop経路として扱わない。ESP32-C3のTWAIはCAN FD非対応なので駆動CAN3へ接続しない |
| mini PC機種 | **GMKtec NucBox G2を採用する(2026-07-19)。** 24V常時通電制御系から12V DC-DCで給電し、E-stop後もGUI・ログ・診断を継続できる構成とする |
| Motor Enable判定 | Teensy側で行う |
| キャリブレーション保存 | 各差動ステアユニットに保存する。**方式はMCU Flashに保存するソフトウェアオフセット**(AMT22内蔵のSet Zero Pointは使わない: 書込ごとにエンコーダNVMを消費し、静止+リセットが必要で、定期再ゼロ点調整の運用と相性が悪い。G4はEEPROM無しのためFlashページのエミュレーションで実装し、CRC付きで保存する) |
| ノード外部接続 | **電源とCANを分離する(2026-07-17)。** 電源は中央基板から各ノードへ5V/GNDをスター分配し、CANはCOMM_A/COMM_B/GNDをバスごとにデイジーチェーン接続する。従来の4線一体ハーネス案はCANがスター状になりやすいため不採用 |
| ユニット抽象化 | 中央からはホイール回転数・ステア角度指令で動作するモジュールとして扱う |
| ユニット基板方式 | **STM32G474直載せの自作基板で確定(2026-07-02)。** Matek CAN-G474を主なファーム開発・検証用、NUCLEO-G474REを予備とする(2026-07-06)。キャリアボード方式(既製ボードのソケット搭載)は不採用 |
| ユニット基板Rev.A DRC基準 | **全ネットクラスの銅箔最小離隔を0.20mmへ統一する(2026-07-24)。** CAN/HSE/ADC/5V/3.3Vとも製造最小0.20mmを下回らない。5V/3.3Vの既定配線幅は0.75/0.40mmを維持し、狭ピッチ部品のパッド直近だけ0.20mmネックダウンを許可する。密集基板のReferenceはF.SilkSで非表示、F.Fab・回路図・BOMを実装時の正本とする |
| ユニットMCU | STM32G474(FDCAN 3系統)。NUCLEOとファームを共用しやすいLQFP64のG474RET6を第一候補 |
| G474実装MCUの調達 | **ユニット基板の実装MCUをSTM32G474RET6(LQFP64、Flash 512KB)で確定(2026-07-17)。10個購入済みで、必要数3個(ユニットx3)に対して試作・交換用予備を確保した。オドメトリ基板は2026-07-25にSTM32F405RGT6へ変更したため、この調達数には含まない(下記「オドメトリ基板MCU変更」参照)。** |
| G474クロック・アナログ電源 | **HSEは8MHz、CL=8pF、ESR max 500Ω、3225-4padを維持し、DigiKey在庫品`FC3BAEBDI8.0-T1`へ変更する(2026-09-06、旧`ECS-80-8-33Q-JES-TR`)。** 負荷容量はC0G 10pF x2の初期値。VDDA/VREF+の1uFは同一定格0603の`C1608X7R1E105K080AB`、VREF+ 10nF C0Gは`C1608C0G1H103J080AA`を調達する。VDDAは`BLM18AG601SN1D`を介し100nF+1uF、VREF+はVDDAへ0Ω接続して10nF+1uF、各VDDは100nF、全体に4.7uFを置く。負荷容量は実基板評価で8.2/10/12pFから最終調整する |
| G474 Reset・監視・基板表示 | **NRSTは内部pull-up+100nF、BOOT0は10kΩ pull-down+隣接BOOT/3V3テストポイント、5V監視は**R13=22kΩ(5V側)/R14=10kΩ(GND側)**+10nF+Comchip `BAT54S-HF`でPA0へ入力する(2026-09-07、旧onsemi `BAT54SLT1G` / Diotec `BAT54S`)。** dual-series、30V、200mA、SOT-23とpin構成を維持する。**分圧は2026-09-21に33kΩ/22kΩ(比0.400)から22kΩ/10kΩ(比0.3125)へ変更**: 実装時に33kΩの現物が無く、在庫のある値で構成し直した。5.00V入力時のADC電圧は2.000V→1.5625V、測定上限は8.25V→10.56V、分圧電流は91µA→156µA。**ファームのADCスケール定数は`Vin = ADC/4095*3.3/0.3125`とすること**(過電圧クランプはD7が担うので分圧比変更による保護の変化はない)。PWR/RUN/COMM/ERRはLite-On C190シリーズの緑/緑/黄/赤を1kΩで駆動し、主要テストポイントはリフロー対応`S1751-46R`とする |
| ユニットID設定 | **3bit DIPスイッチで確定(2026-07-20)。DigiKey在庫0の`A6S-3104-H`から、既存ランド互換を確認した`DS04-254-1-03BK-SMT`へ変更する(2026-09-06)。** UNIT_ID0/1/2=PC6/PC7/PC8、内部プルアップ、スイッチON=GND短絡(読み値は反転)。起動時に1回読み取り、RUN LEDをID回数点滅させて目視確認できるようにする。全OFF(ID=0)は未設定としてエラー扱い。DS04の推奨ランドは列中心間8.9mm、縦pitch 2.54mm、pad 1.5x1.1mmで既存KiCad A6S footprintと一致する |
| 中央-ユニット通信 | **CANで確定(2026-07-02)。** 中央CANとC620専用CANの2バス構成。FDCANを2系統使う |
| C620通信 | ユニット内部CANに閉じ込める |
| ベンチ検証用ボード | **購入済みMatek CAN-G474を主試験機、CAN-L431を1バスの対向ノード、NUCLEO-G474REを予備とする(2026-07-06)。** CAN-G474はG474+CAN 2系統のため最終構成に近い。ただしG474CEとG474REでパッケージ・露出ピンが異なるため、ボード別ピン設定で検証する |
| 回路設計の参考 | **Matek CAN-L431、Matek CAN-G474、ARK CANnode、CANable 2.0を参照する(2026-07-06)。** L431/G474の実装・公式ピン情報、ARK CANnode/CANableの公開回路をブロック単位で比較し、G474自作基板へ適合確認して採用する。基板全体を無検証で複製しない |
| 中央制御 | Teensy 4.1で確定(2026-07-02) |
| 駆動ユニット配置 | **車体中心から半径250mmの円上へ3ユニットを120°間隔で配置する(2026-07-31)。** 車体`+X前・+Y左`でセンサーモジュール搭載辺をunit 1–3間の`+Y`側とし、unit 1=`(-216.5,+125)mm`、unit 2=`(0,-250)mm`、unit 3=`(+216.5,+125)mm`とする。公称車輪径は65mm(半径32.5mm)。実走距離校正時は実効半径で中央設定を上書きする |
| 中央CANバス分離 | **Teensy 4.1のCAN3(CAN FD対応)を駆動ユニットx3専用、CAN1をオドメトリ/IMU等のセンサーノード専用、CAN2を汎用拡張/予備とする(2026-07-31、旧2026-07-17割当を更新)。** 駆動指令・安全系トラフィックをセンサートラフィックから分離する |
| CAN方式・速度 | **Teensy-CAN3/G474-FDCAN1間の駆動中央バスはCAN FD、nominal 1Mbps/data 2Mbps、BRS有効とする(2026-07-31、旧2026-07-19の全Classic方針を更新)。** `TCAN1051VDRQ1`はTI仕様上CAN FD 2Mbps対応のためBOM変更不要。G474-C620専用CANとF405オドメトリ/IMUのセンサーCANはClassic CAN 1Mbpsを維持する。駆動FDバスは標準11bit ID、最大64byte payloadを使い、G474局所1kHz補間用の時刻付き軌道を200〜250Hzで送る |
| 部品選定基準 | **回路部品は入手性、少量価格、複数の公開プロジェクト・メーカー評価基板での採用実績、信頼性、ステンシルリフローおよび修理のしやすさを総合評価して選定する(2026-07-19)。** 正規流通でActive品を優先し、単一マーケットプレイス依存品、BGA/WLCSP、0201以下、検査・交換困難なパッケージは原則避ける。受動部品は0603以上、ICはLQFP/SOIC/TSSOP/SOT系を優先し、QFN/露出パッド品は明確な利点と実装条件がある場合に採用する |
| ノード給電 | **購入済み24V→5V/5A DC-DCから中央基板へXT30で入力し、ユニットx3・オドメトリ基板の各枝を`1206L050/15YR`で個別保護して横挿しGH2からスター分配する(2026-07-19)。** ユニット基板とオドメトリ基板は`LM66100DCKR`の`CE_N`をVOUTへ接続するRPP+RCB構成で逆接・逆流保護し、3.3V LDOは`TLV1117LV33DCYR`生産中止に伴い、同一SOT-223ピン配置・1A・セラミック安定の`TLV76133DCYR`を実装する(2026-09-06変更)。Teensy枝と中央5A主入力の保護は負荷条件が異なるため別途選定する |
| バッテリー監視 | バッテリー電圧・電流監視を追加し、監視ノード/ICを中央TeensyのI2Cバスへ接続する(2026-07-17)。監視IC、シャント、絶縁方式は部品選定時に確定する |
| 中央5V主入力保護 | **中央基板の5V主入力は`XT30PW-M`から`TPS259470LRPWR`へ通す(2026-08-04、2026-09-12具体化)。** 内蔵back-to-back FETで真の逆流阻止・突入・過電流・過熱・逆極性を保護し、`RILM=750Ω`のtyp 4.45Aを初期値とする。SD-25B-5を5.00Vへ調整・封印、UVLO/OVLO dividerは1% `732k/51.1k/221k`（typ 4.43V/5.46V）。中央5A経路に1.5A定格LM66100や別series diodeは追加しない。TeensyのVUSB-VIN padは切断する |
| 中央バッテリー監視回路 | **購入済みMatek `I2C-INA-BM`へ変更する(2026-09-12、2026-08-04のINA238+外付けshunt決定を置換)。** 内蔵200uΩ typシャントを使い、主電流は中央PCBへ流さず外部モジュールのBAT+→ESC+へ直列配置する。中央基板はI2C0のGH4（G/SDA/SCL/+5V_SYS）だけを出す。既定addressは69(0x45)。I2Cのpull-up電圧がTeensy安全な3.3Vであることを通電前に確認する |
| 中央E-stop監視・再アーム | **直列NCループと補助接点x2は`LTV-847S`で絶縁監視し、再励磁にはGUI要求だけでなく独立した物理再アーム操作を必須とする(2026-08-04)。** コンタクタdriverは`IRLML0100TRPBF`+diode/TVS clamp、操作panel connectorはMicro-Fit 3.0 single-row 6pin (`43650-0600`/`43645-0600`)とする。物理buttonのboard/panel配置だけは機体layoutで確定する |
| 中央基板 設計憲法 | **中央基板Rev.1の最上位設計方針を`CENTRAL_BOARD_REV1_CONSTITUTION.md`に固定する(2026-09-12)。** 「USBだけでも開発でき、24Vを入れれば実機運用でき、24V+USBでは実機を動かしながらデバッグできる」を最上位ルールとする。他の中央基板ドキュメントと矛盾する場合はこのファイルを正とする |
| 中央基板 24V負荷出力の分離方針 | **電磁弁・リレー・ソレノイド・ブザー等の汎用24V/12V負荷駆動は独立CANノードへ切り出すが、メインコンタクタだけは安全系として別扱いにする(2026-09-14、2026-09-17明確化)。** 中央PCBには汎用N-MOSローサイド出力もコイルMOSFETも搭載しない。コンタクタは別体`CONTACTOR_DRIVER`へ中央Teensyの3.3V `MOTOR_PWR_EN`とハードE-stop NCループを直接配線し、CANノードを経由しない。 |
| 24V/12V機器操作CANノード | **12〜24V自己給電の独立CANアクチュエータノードを新設する(2026-09-14)。** 中央とのハーネスはCAN 2線(`COMM_A/B`)だけ。F303K+TCAN1051でCAN2を受け、局所Buckで5V/3.3Vを生成し、汎用24V出力と小型DCモーターHブリッジをローカル制御する。 |
| 24VアクチュエータCANノード Rev.A仕様 | **独立CANノードは`STM32F303K8T6`+`TCAN1051VDRQ1`+`LMR51606XDDCR`を採用し、24V/1A汎用ローサイド4ch、24V小型ブラシDCモーター用`DRV8251ADDA` Hブリッジ1chを持つ(2026-09-14更新)。** `VIN_ACT`は12〜24V nominal、中央とはCAN 2線のみ。Hブリッジは連続1.5A・短時間3Aまで。C620/走行輪・主電流・回生chopperには使わない。CAN timeout/MCU reset/watchdog/ESTOP broadcastで全出力OFF、再アーム必須。コンタクタQ1はノードに含めず中央側`CONTACTOR_DRIVER`ブロックへ移す。詳細正本は`docs/electrical/ACTUATOR_CAN_NODE_REQUIREMENTS.md` |
| 中央基板 汎用CAN拡張ポート | **5V/GND/CANH/CANLを4pin一体にした汎用CAN拡張ポートを新設する(2026-09-12)。適用範囲はこの新設ポートのみに限定する。** 既存のユニット基板・オドメトリ基板への内部ハーネスは2026-07-17確定の電源/CAN分離・デイジーチェーン方式を維持し、混同しない。**ただし2026-09-14追加の自己給電アクチュエータ/LED CANノードはこの5V/GNDを使わず、中央との実ハーネスを`COMM_A/B`の2線にする。** |
| 中央基板 メインコンタクタ名称 | 「TN686」は2026-09-12の設計憲法内でKILIGEN E228を指す一般名として使われただけで、部品変更ではない。2026-07-26確定のE228採用・実績データをそのまま継続する |
| 中央基板CANトランシーバ再検討 | **`TCAN1051VDRQ1`を維持する(2026-09-12再確認)。** 部室在庫のROHM `BD41044FJ-CE2`を代替候補として実データシート確認したところ、単一VCC 4.75〜5.25V供給でTXD/RXD/STBもVCC基準ロジック(VIH_TXD min 0.7×VCC、RXD出力HIGHはVCC-0.4V)であり、VIO=3.3V直結ピンを持つ`TCAN1051VDRQ1`と異なりTeensyの3.3V専用GPIOへレベルシフタなしで直結できない。手持ち品の節約額(数百円)に対しレベルシフタ追加・回路図再設計のコストが見合わないため不採用とする |
| 中央基板 拡張ヘッダ保護 | **全拡張ヘッダ(I2C x2/UART x2/SPI/GPIO x8)へ`SRV05-4`(SOT-23-6、4ch低容量TVSアレイ)を追加する(2026-09-12確定)。** 後輩・後続プロジェクトが雑に配線しても壊れにくい汎用CANマスタボードを狙う。pin5(VCC/steering)は`+3V3_TEENSY`、pin2はGNDへ接続し3.3Vロジックとして使う |
| 中央基板 拡張ヘッダLED | **主要ポート(CAN/UART/SPI等)にアクティビティLEDを追加するが、新規Teensy GPIOは消費しない(2026-09-12確定)。** 既存の信号ネット(TXD/RXD/SCK等)へdigital transistorで直接タップし駆動する。Rev.Aで予備にしているTeensy pin 33/37/38/39は温存する |
| 中央基板 USB給電 | **VUSB-VINパッドカットは維持しつつ、`+5V_SYS`とVUSBそれぞれから1A級Schottkyでdiode-ORしてVINへ供給する(2026-09-12確定)。** システム24Vを入れずにUSB単体でもTeensyが起動でき、ベンチ書き込み時の運用が簡素になる。**2026-09-26追記: USBから`+5V_SYS`へも第2 eFuse経由で給電する構成へ拡張（上の「中央基板 USB単独給電の範囲」参照）。「外部5V枝をUSBから給電させない」は撤回** |
| 中央基板 Rev.1 憲法 | **中央基板を外部5V入力案から、`24V_IN + USB`を入力とするRev.1へ移行する(2026-09-12)。** 基板上24V→5V Buckと優先ORingによりUSBのみ/24Vのみ/24V+USBを成立させる。中央基板にコンタクタ・24Vローサイド出力は載せない(2026-09-14変更、「24V/12V機器操作CANノード」参照)。モータ・大電流LED等も引き続きCAN子基板または外部電力系へ分離する。E-stop NC loopはMCU非依存でコイルを遮断し、危険出力はReset/Hi-Z/crash/CAN lossでOFFとする。詳細と終了条件は`electrical/CENTRAL_BOARD_REV1_CONSTITUTION.md`を正本とする |
| 中央基板 Rev.1 Buck | **2026-09-12確定の「中央基板に24V→5V Buck(LM76005)を内蔵する」を撤回する(2026-09-14)。** 外部24V→5Vモジュール(`SD-25B-5`、5.00V封印)で降圧済みの5Vを中央基板XT30へ入力する旧方式に戻す。中央基板側はTI `TPS259470LRPWR`による5V eFuse(UVLO/OVLO 1% `732k/51.1k/221k`、`RILM=750Ω`)以降を担当する。詳細は`electrical/CENTRAL_BOARD_REQUIREMENTS.md`。`CENTRAL_BOARD_POWER_BLOCK_REV1.md`のLM76005内蔵Buck設計は不採用(参考として残す) |
| 中央Teensy実装 | **Teensy 4.1はPJRC推奨24x1 socket x2 (`PPPC241LFBN-RC`/`PPTC241LFBN-RC`)へ実装し、48本の表面through-hole pinだけをRev.Aで使う(2026-08-04)。** CAN3=Drive FD、CAN1=Sensor、CAN2=Expansionとし、詳細pin mapは`TEENSY41_CENTRAL_PIN_ASSIGNMENT.md`を正本とする。Teensy直下は全面keepoutにする。**Teensy pin 33/37/38/39は未使用とし、ソケットpinへNo Connectを付け、基板内テストパッドにも引き出さない(2026-08-05)。** |
| エンコーダ取付 | AMT22はステア軸に直結(1:1)。絶対角がそのままステア角になる |
| エンコーダ型式 | **AMT222A-V**(12bitシングルターン、radial、5mmボア)で確定(2026-07-02)。分解能4096cnt = 0.088°/cnt |
| オドメトリ | 3輪オドメトリ構成、専用のSTM32F405基板(unitId=4、2026-07-25にG4系列から変更)で基板上のx/y/θ計算・中央CAN配信は維持。**センサはAMT102 x3へ戻す(2026-07-08)。Z相は使わず、4線(VCC/GND/A/B)のみでTIM2/TIM3/TIM4のEncoder Modeへ入力する。** I2Cホール磁気エンコーダ案(MT6701/AS5600、2026-07-06案)は、測定輪シャフトへの磁石・センサ位置合わせの機械接続が難しいため廃止。詳細は`ODOMETRY_BOARD_REQUIREMENTS.md` |
| オドメトリ/IMU基板 | **ユニット基板とは別形状の自作PCBとし、共通回路ブロックだけを流用する(2026-07-17)。** STM32F405RGT6(2026-07-25変更、旧STM32G474RET6)にSPI IMUを追加可能な状態推定ノードとし、AMT102オドメトリとの融合結果をセンサーCANへ配信する。IMU型番は未確定 |
| オドメトリ基板MCU変更 | **オドメトリ基板のMCUをSTM32G474RET6からSTM32F405RGT6(LQFP64)へ変更する(2026-07-25確定)。** 部室在庫から発掘した個体を使い、購入済みG474RET6の消費数を1個減らす狙い。オドメトリ基板はセンサーCAN1系統のみ必要で、ユニット基板がG474を選んだ決め手だった「FDCAN 2系統必要」という制約が掛からないため成立する。センサーCANはClassic CAN 1Mbps固定(上記「CAN方式・速度」)でCAN FDの機能を使わないため、F405の`bxCAN`(Classic CAN専用)で要件を満たす。VCAP_1/VCAP_2用2.2µFの追加、HSEのPF0/PF1→PH0/PH1移動、デバッグUARTのLPUART1→USART2、BOOT0の専用ピン化など回路上の差分は`ODOMETRY_BOARD_REQUIREMENTS.md`と`STM32F405_ODOMETRY_PIN_ASSIGNMENT.md`に記載。ユニット基板・中央基板はG474/Teensyのまま変更しない |
| オドメトリ基板部品流用 | **F405固有のMCU最小回路を除き、unit boardの確定部品・共通ブロックを優先流用する(2026-07-25確定)。** `LM66100DCKT`（DCKRと梱包差のみ）、`TLV76133DCYR`、`TCAN1051VDRQ1`、`FC3BAEBDI8.0-T1` 8MHz HSE、`C1608X7R1E105K080AB` 1uF、`DS04-254-1-03BK-SMT`、GHコネクタ、LED、SWD/UART回路を基本共通とする(調達型番は2026-09-06更新)。F405固有でVCAP 2.2µF x2を追加し、LDOの電流・熱、HSE負荷容量はF405実基板で再検証する |
| オドメトリIMU | **`ICM-42688-P`搭載8pinブレークアウトモジュールを採用し、2026-07-25購入済み。** モジュール表記は`VCC/GND/AD0(MISO)/SDA(MOSI)/SCL(SCLK)/CS/INT1/INT2`。F405 SPI3を4-wireで使用し、PC10=SCK、PC11=MISO、PC12=MOSI、PD2=`IMU_CS_N`、PC4=`IMU_INT1`(Data Ready)、PC5=`IMU_INT2`(予備)とする。モジュールは5V/3.3V給電対応表記だが、F405との信号電圧を揃えるため3.3V給電固定とする。基板へ剛結し、pin 1方向、pitch、外形、固定穴、オンボード回路は到着後に実物確認する |
| オドメトリ回路図構成 | **Rev.A回路図は階層シートを使わず、A3横1枚のフラット構成とする(2026-07-25確定)。** 電源、F405、CAN、AMT102 x3、IMU、Debug/ID/LEDを機能ゾーンで分離し、短いスタブ+通常のローカルネットラベルで接続する。旧G474階層シートは履歴として残すが新回路図から参照しない |
| オドメトリAMT102入力保護 | **AMT102 A/B入力は各コネクタに`ESDS452DBZR`を1個、合計3個使用する(2026-07-25確定)。** 5V信号に対応する5.5V working・2ch双方向TVSをコネクタ直近へ置き、connector -> TVS -> 100Ω初期値の直列抵抗 -> `SN74LVC2G17DBVR` -> F405の順とする。RCはDNP footprintのみ用意し、必要性と定数は実測波形で決める |
| mini PC接続 | GUI・設定・ログ用のTeensy 4.1ネイティブUSB(micro USB、USB-CDC)は維持する。手動DualSense指令だけはmini PC→ESP32-C3のWi-Fi/UDP→Teensy CAN2経路とする。CAN-to-USBはバス監視・デバッグ用途(CANable等)に使う |
| ゼロ点調整 | 毎回は不要だが、チャックと軸のずれを想定して定期的な再ゼロ点調整を運用に組み込む |
| コネクタ | **ロボット側の小電流信号・電源・G474デバッグはロック付きJST GHへ統一する(2026-07-19)。** 中央基板の5V主入力はXT30等、バッテリー主電源はXT90-Sを維持。G474各基板は上挿しGH 6pin `BM06B-GHS-TBT` (`GND/SWCLK/SWDIO/NRST/DBG_TX/DBG_RX`)とし、WeActStudio MiniDebugger側SH 10pinとの専用変換ケーブルを使う。デバッガの5V/3.3V出力は接続せず、ターゲットは自己給電する |
| CAN配線・終端 | **2026-09-23最終指定: 専用CANコネクタは横挿しJST GH 3pin（1=COMM_A、2=COMM_B、3=GND）に統一する。** 同日の駆動V2/ODOM V2 CAN2pin案を撤回。中央CAN1/2/3、駆動/ODOM、LED/スイッチングCAN接続へ適用。既存汎用4pinポートとC620純正ハーネスは別仕様。デイジーチェーンと物理両端のみ120Ω終端を維持。 |
| 協調制御の責務分担 | **車体軌道(ツイストプロファイル)生成・3輪同時目標算出・飽和デサチュレーション・ステア反転判断はすべて中央Teensyで行う(2026-07-06)。** ユニットはFF付き追従と安全ガードのみで、軌道の形を変えない(独自のランプ・反転・配分をしない)。詳細は `docs/control/CENTRAL_COORDINATED_CONTROL.md` |
| 目標値FF配信 | **SET_TARGET_FF(0x110+id、ステア角速度FF+ホイール加速度FF)を中央CANへ追加(2026-07-06)。** 目標ステア角は連続unwrap角(±180°で折り返さない)。FF未受信時はFF=0で従来動作(後方互換) |
| 明示ステア加速度のベンチ移行経路 | **CAN FD軌道実装前の単体Classic CANベンチに限り`SET_TARGET_ACCEL_FF(0x160+id)`でステア角加速度を200Hz配信する(2026-07-31)。** G474はfreshな明示値を受信周期差分より優先し、200ms途絶時は従来差分へ戻る。本番3輪制御では同じ値を`TRAJECTORY_FD.thetaDDot`へ統合し、この互換IDを使わない |
| 駆動目標の加減速・停止 | **中央Teensyは`ωw`をステップ送信せず、加速・減速を別レートにしたランプを通す(2026-07-31)。** 高rpmからの急減速・直接の正逆反転は回生によるDCバス電圧上昇と電源保護停止を招くため禁止し、反転は必ず0rpmを経由する。通常STOPは`現在rpm/減速率+余裕時間`だけ閉ループ減速してからdisableする。E-stop/緊急Disableは安全を優先し、この通常停止シーケンスの例外とする |
| ステア目標の加速・制動 | **中央のステアプロファイルは加速率と制動率を別パラメータにする(2026-07-31)。** 最大速度へ早く到達する加速率と、局所追従遅れを見込んで減速開始を決める制動率を分離する。単一ユニット空走初期値は最大240deg/s、加速3600deg/s^2、制動2250deg/s^2。3輪実装では中央が同一時刻断面を生成し、ユニットが独自に軌道形状を変更しない責務分担を維持する |
| 高速ステア局所制御 | **100rpm超は固定PI/FFのまま電流上限だけを上げず、steer reference/observer速度に応じた連続ゲインスケジューリングをG474へ導入する(2026-07-31)。** 0〜60rpmの採用値を維持し、速度knot間でKp/Ki/加速・制動FF/anti-windup gainを線形補間する。4000rawでschedule・back-calculation・明示加速度FFを成立させ、加速中の電流不足が計測で確認された場合だけ4500以上へ段階拡張する。詳細は`docs/control/HIGH_SPEED_STEER_GAIN_SCHEDULING_PLAN.md` |
| 到着時間と収束完了 | **中央の通常軌道は10% motor-rpm予備を持つplanned包絡線で最短時間を計算し、初期time scaleを2.0とする(2026-07-31)。** 3輪を個別時間で動かさず、最遅モジュールに全体を同期する。軌道時間と追従収束は分離し、各ユニットはSTATUS3の`MOTION_SETTLED`(角度・実steer rpm・wheel追従・steer/wheel FF停止を100ms継続)を返す。中央は全輪フラグと自分のプロファイル完了を確認して到着確定する。空走初期の監視余裕は軌道終了後0.35sで、接地後のp99実測に更新する。期限超過時は制約を破って指令を強めず、ETA延長・全体減速・必要時停止とする |
| 高速ステア調整の実用合格基準 | **unit 1浮上状態の応答優先commissioningは、全試行で安全停止なし、目標±2deg初回到達0.50s以下、overshoot 20deg以下、終端誤差1deg以下を使う(2026-07-31、旧8degからユーザー方針で緩和)。** 厳格なovershoot 4deg/settle 0.9sは診断列として残す。20deg基準は接地3輪へ流用せず車体横振れを含め再設定する。`MOTION_SETTLED`自体と中央の全輪到着確認は廃止しない |
| ユニット内ステアrate rampの責務 | **G474の`steer_accel_rpm_per_s`は通常軌道生成ではなく、中央指令異常・legacy senderに対する最終hard guardとする(2026-07-31)。** boot既定600rpm/sは安全な単体起動用に維持し、runtime上限は4000rpm/s。通常運転では中央profileの最大加速度より十分高く設定して二重rampを避ける |
| 負荷適応制御の発展順序 | **現行mode PIを土台に、FF強化→摩擦補償→mode-space DOB→状態推定→必要時MPCの順で進める(2026-07-09)。** G474は1kHz局所ロバスト制御(PI+FF+DOB)と安全ガードに集中し、3輪協調・制約最適化・MPC候補はTeensy/mini PC側へ置く。詳細は `docs/control/LOAD_ADAPTIVE_CONTROL_ROADMAP.md` |

## 差動ステアユニットの抽象化

中央制御から見た差動ステアユニットは、C620やM3508を直接操作する対象ではなく、以下のような高レベルのCANノードとして扱う。

中央からユニットへ送るもの:

- 目標ホイール回転数
- 目標ステア角度
- 有効/無効指令
- キャリブレーション指令

ユニットから中央へ返すもの:

- 現在ホイール回転数
- 現在ステア角度
- モーター状態
- AMT22状態
- エラー状態
- キャリブレーション状態

ユニット内部では、NUCLEO-G474REがAMT22の絶対角とC620のフィードバックを統合し、2個のM3508へ差動指令を出す。

## 通信構成の決定

**2026-07-02にG474のFDCAN複数系統を根拠として中央通信をCANへ確定し、下記A案(RS485)を不採用とした。2026-07-06に主試験機をCAN 2系統のMatek CAN-G474へ変更したが、採用構成「2バスCAN」と最終G474RET6自作基板は変更しない。**

目標は、中央から各ユニットへ `VIN_CONTROL / GND_CTRL / COMM_A / COMM_B` の4線だけを通し、C620の存在をユニット内に隠すこと。この抽象化は物理層がCANになっても変えない。

```text
中央駆動通信 (G474 FDCAN1、CAN FD nominal 1Mbps/data 2Mbps):
  Teensy <--> 各ユニットMCU     COMM_A/B = 中央CAN_H/L

ユニット内CAN (FDCAN2想定、1Mbps固定):
  ユニットMCU <--> C620 #1
              <--> C620 #2

センサー通信 (Teensy CAN1、Classic CAN 1Mbps):
  Teensy <--> F405オドメトリ/IMU
```

中央CANにはC620の生IDやフィードバックを流さない。中央からはユニット単位の抽象化されたメッセージだけを見る。ユニットMCUはトランシーバを2個持つ(中央用+C620用)。

## 候補構成(検討記録。結論は上記の通り2バスCAN)

### 採用案: 2バスCAN構成

```text
Teensy
  |
  | 中央CAN (COMM_A/B)
  v
ユニットMCU (G474RE, FDCAN x2使用)
  |
  | C620専用CAN
  v
C620 x2
```

利点:

- A案と同じくC620を中央から完全に隠せる。
- RS485のような独自フレーム設計・CRC・半二重の送受切替が不要。CANのアービトレーション・CRC・ACKをそのまま使える。
- Teensy 4.xのFlexCANと直接つながる。
- ユニット側ファームはFDCANドライバ1本で中央・C620の両方を扱える。

成立条件:

- ユニットMCUにFDCANが2系統必要。**G474REはFDCAN 3系統なので成立**(G431KBは1系統で不成立。これがボード確定の決め手)。
- キャリアにCANトランシーバが2個必要。

### A案(不採用): RS485 + 内部CAN構成

```text
Teensy
  |
  | RS485 4線
  v
ユニットMCU
  |
  | ユニット内CAN
  v
C620 x2
```

利点:

- 中央からC620を完全に隠せる。
- ユニットが本当に自己完結モジュールになる。
- ユニットMCUのCANをC620専用にできる。
- NUCLEO-G431KBのCANが1系統でも成立しやすい。

課題:

- RS485用のパケット設計とCRCが必要。
- 中央主導のポーリング方式にする必要がある。

### B案: 1 CAN共有構成

```text
Teensy
  |
  | CAN共有バス
  |-- ユニットMCU x3
  |-- C620 x6
```

利点:

- ハードウェアが単純。
- NUCLEO-G431KBのCAN 1系統でも成立しやすい。

課題:

- 中央CANにC620の生IDが流れる。
- ユニット抽象化はソフト上の約束になる。
- CAN帯域とID設計をより厳密に管理する必要がある。

### C案: 外付けCAN追加

```text
中央CAN: STM32内蔵FDCAN
C620 CAN: 外付けCANコントローラ + トランシーバ
```

利点:

- NUCLEO-G431KBを使いつつ、2 CAN構成に近づけられる。

課題:

- 部品が増える。
- 手ハンダ性、ファーム実装、基板面積が悪化する。

## 現時点の結論(2026-07-02)

G474のFDCAN複数系統を使用して2バスCAN構成を採用する。主試験機はMatek CAN-G474、NUCLEO-G474REは予備とする。A案(RS485)はG431KB前提の検討記録として残す。

外部コネクタのシルクは従来方針通り `CAN_H/L` ではなく `COMM_A/B` とする。物理層がCANでも抽象名を保つことで、将来の変更に外部仕様名を保てる。

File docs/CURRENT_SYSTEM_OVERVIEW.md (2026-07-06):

# CURRENT_SYSTEM_OVERVIEW.md

# Robotics Platform - Current System Overview

> Last Updated: 2026-06-26

---

# Goal

ロボットごとに電子回路やソフトウェアを作り直すのではなく、
再利用可能なモジュール群を構築する。

最終的には各モジュールを組み合わせるだけで新しいロボットを開発できることを目標とする。

---

# Overall Architecture

```
                Jetson / MiniPC
                       │
        ┌──────────────┴──────────────┐
        │                             │
    Motor Network                Sensor Network
        │                             │
  Drive Unit ×3                Sensor Fusion Node
        │                             │
        │                        LiDAR Node (Future)
        │
   Power Distribution
```

---

# Planned Modules

## 1. Drive Unit Controller (Highest Priority)

### Purpose

差動ステアユニットをローカルで制御する。

中央からは

* target RPM
* target Steering Angle

のみを受け取り、

内部で

* Steering PID
* Drive PID

を実行する。

---

### Hardware

* STM32G4 Series
* C620 ×2
* M3508 ×2
* AMT222 Absolute Encoder
* CAN
* USB-C Debug

---

### Inputs

* target_rpm
* target_steering_angle

---

### Outputs

* current_rpm
* current_steering_angle
* motor_current
* temperature
* status

---

### Internal Control Loop

1000Hz

* Read CAN Feedback
* Read AMT222
* Steering PID
* Drive PID
* Send Current Command

---

# 2. Sensor Fusion Node

### Purpose

自己位置推定用センサーノード

ロボット本体とは独立した汎用センサモジュールとする。

---

### Hardware

* STM32G4 Series
* IMU ×1
* Encoder ×3
* CAN
* USB-C

---

### Outputs

* x

* y

* theta

* vx

* vy

* omega

* raw encoder

* gyro

* accel

* status

---

### Future

LiDARとのセンサフュージョンを前提とする。

---

# 3. Odometry Unit

### Purpose

取り外し可能な自己位置推定ユニット

構成

* Omni Wheel ×3
* Encoder ×3
* Sensor Fusion Board

通信

* CAN
* Power

のみで動作することを目標とする。

---

# 4. LiDAR Node (Future)

未設計

将来的に

* LiDAR
* IMU
* Scan Matching

を担当する独立ノードとする予定。

---

# Common Design Rules

## MCU

STM32G4 Series

**確定(2026-07-02): STM32G474(NUCLEO-G474RE)。** FDCAN 3系統が決め手。

---

## Communication

**確定(2026-07-02): 2バスCAN(中央CAN + C620専用CAN、各クラシックCAN 1Mbps)。** RS485案は廃止。

---

## Debug

USB Type-C

---

## Logic Voltage

3.3V

---

## Input Voltage

TBD

(24V想定)

---

## Coordinate System

```
+X : Forward

+Y : Left

+Theta : Counter Clockwise
```

---

# Software Philosophy

各モジュールは

"入力 → 処理 → 出力"

のみを担当する。

上位から見ればブラックボックスとして扱える設計を目指す。

---

# Future Modules

候補

* Power Distribution Board
* CAN Logger
* IO Expansion Board
* Battery Management Board
* USB Debug Adapter
* Wireless Debug Module

---

# Open Issues

* ~~STM32G431 or STM32G474~~ → STM32G474で確定(2026-07-02)
* ~~CAN FD採用~~ → 当面クラシックCAN 1Mbps(C620が1Mbps固定のため。中央CANのFD化は将来検討)
* 電源構成 → `electrical/POWER_DISTRIBUTION_AND_ESTOP.md` にパーツ選定済み
* IMU選定
* Connector規格
* ~~CAN ID規則~~ → `communication/COMMUNICATION_NAMING_AND_IDS.md` に中央CAN ID案を記載

---

# Development Roadmap

Phase0

* 全体仕様策定

Phase1

* Drive Unit Controller

Phase2

* 3 Unit Integration

Phase3

* Sensor Fusion Node

Phase4

* Odometry Unit

Phase5

* LiDAR Integration

---

# Design Philosophy

設計の目的は

「一台のロボットを完成させること」

ではなく

「再利用可能なロボットプラットフォームを構築すること」

とする。

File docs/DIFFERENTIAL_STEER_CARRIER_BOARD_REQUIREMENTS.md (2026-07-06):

# 差動ステアユニット基板 設計要件・注意点

> **注意: このファイルは旧版の詳細メモ。正本は `electrical/CARRIER_BOARD_REQUIREMENTS.md`。**
> 特に以下は正本側で結論が更新済みであり、本ファイルの記述は古い。
>
> - AMT22はデータシート確認済み(VIH min 2.0V、出力High 3.3V)。**全信号3.3V直結でよく、MISO分圧・バッファ・5Vトレラントピン要件は不要。**
> - LDOはAMS1117ではなくMCP1826S-3302を第一候補に変更。
> - **搭載ボードはNUCLEO-G474REで確定(2026-07-02)。G431KB前提の記述はすべて旧い。**
> - **中央通信はRS485ではなくCANで確定(2バスCAN構成)。** 本ファイルのRS485関連記述は不採用案の記録。

## 方式

NUCLEO-G431KB を載せるキャリアボード方式とする。

1ユニットの構成は以下。

| 要素 | 数量 |
|---|---:|
| M3508 | 2 |
| C620 | 2 |
| AMT22 | 1 |
| NUCLEO-G431KB | 1 |

## 0. 設計思想

- 各ユニットは自己完結した知能を持つ部品として扱う。
- 挿す位置を変えても同じファームで動く。ユニットIDだけを振り直す。
- ユニット内MCUで2モータ協調、方位ループ、速度ループを閉じる。
- 中央Teensyへは目標角と目標速のみを送り、ステータスは間引いて返す。
- リフローやQFNハンダを避けるため、MCU最小構成はNUCLEO-G431KBに任せる。
- キャリアボード側は手ハンダ可能な部品だけで構成する。
- 第一段階はキャリアボードで実証する。
- 第二段階として、必要になったら裸チップ基板へ移行する。

## 1. 外部インターフェース要件

ユニットが外部と接続する線は以下。

| 信号 | 電圧/種別 | 用途 | 備考 |
|---|---|---|---|
| 24V | 電源・大電流 | C620 x2 駆動 | XT30等、電流定格のあるコネクタ |
| 5V | 電源・小電流 | 制御系 | 中央分電盤で 24V から 5V に降圧済み |
| GND | 共通 | 基準、リターン | スターGNDの一端 |
| CAN_H / CAN_L | 差動信号 | 制御バス | 小信号コネクタ |

前提:

- 配線が短い前提で、中央集約降圧を採用する。
- 各ユニットからDC-DCとインダクタを省き、基板を小型化する。
- C620 x2 とのCAN接続、AMT22とのSPI接続はユニット内コネクタで受ける。

## 2. 電源系

### 構成

```text
6S LiPo x2
  |
  |-- 24V系メイン分電盤
        |-- 24V --> C620 x6
        |-- 24V --> DC-DC 24V->12V --> mini PC
        |-- 24V --> DC-DC 24V->5V  --> 中央Teensy / センサ / 各ユニット制御基板

各差動ステアユニット:
  24V --> C620 x2
  5V  --> キャリアボード
  5V  --> AMT22
  5V  --> LDO AMS1117-3.3 --> 3.3V MCU / CANトランシーバ
```

6S LiPo x2 は、基本的に同電圧のまま電流容量を増やす構成として扱う。直列接続すると12S相当、満充電で約50.4Vになり、C620系には危険。

可能な構成は以下。

| 構成 | 電圧 | 用途 |
|---|---:|---|
| 6S x2 並列 | 約22.2V、公称 | 推奨。C620 x6へ共通分配 |
| 6S x2 独立系統 | 約22.2V、公称 x2 | 左右・前後などで分ける場合。GND共通化に注意 |
| 6S x2 直列 | 約44.4V、公称 | 非推奨。C620に入れない |

### バッテリ差し替えと並列バランス

6S LiPo x2 を差し替えやすくする場合でも、単純な並列直結は避ける。

理由:

- 電圧差のあるLiPo同士を直結すると、大きな突入電流が流れる。
- 片方のバッテリからもう片方へ逆流する可能性がある。
- 差し替え時にC620やDC-DCの入力コンデンサへ突入電流が流れる。

推奨構成:

```text
6S LiPo A -- ヒューズ -- 逆流防止/理想ダイオード --+
                                                   +-- プリチャージ -- メインリレー -- 24Vバス
6S LiPo B -- ヒューズ -- 逆流防止/理想ダイオード --+
```

要件:

- 各LiPoの直後にヒューズを入れる。
- 2本のLiPoを並列化する前に、電圧差を確認できるようにする。
- 電圧差が大きい状態で並列接続しない。
- 逆流防止としてショットキーダイオード、または理想ダイオード回路を検討する。
- 大電流用途なので、発熱と電圧降下の小さい理想ダイオード方式が望ましい。
- メイン24Vバス投入前にプリチャージ経路を用意し、DC-DCやC620入力コンデンサへの突入を抑える。
- バッテリ交換用コネクタは、抜き差ししやすさより電流定格と接触信頼性を優先する。

運用ルール:

- 交換前にLiPo A/Bの電圧差を確認する。
- 電圧差が大きい場合は並列運用しない。
- 充電状態の異なるパックを混ぜない。
- 可能なら同型・同容量・同劣化度のパックをペアで使う。

制御系のユニット間ハーネスは、基本を4線にする。

```text
CAN_H
CAN_L
VIN_CONTROL
GND
```

ここで `VIN_CONTROL` は各ユニット制御基板へ配る5Vを指す。C620用の24V大電流ラインは、この4線とは別に太線で分配する。

### 注意点

- 6S満充電電圧は約25.2V。C620の絶対最大定格を超えないかデータシートで確認する。
- 6S LiPo x2 を直列にしない。直列時は満充電で約50.4Vになる。
- C620 x6 へは24V系をそのまま分配する。
- mini PC へは24Vから12Vへ降圧して供給する。
- 中央Teensy、センサ、各ユニット制御基板へは24Vから5Vへ降圧して分配する。
- 中央5V DC-DCは5V/3A以上を最低ラインとし、余裕を見て5A品を採用する。
- mini PC用12V DC-DCは、mini PCのピーク電力に合わせて別途選定する。
- 5VラインがAMT22の上限を超えないよう、レギュレーションの良いバックコンバータを選ぶ。
- AMS1117-3.3は、5V入力から3.3V出力なのでドロップアウト余裕はある。
- LDOとトランシーバ近傍には0.1uFを置く。
- LDO出力側には数uF以上のバルクコンデンサを置く。

### 非常停止

非常停止は、ソフト停止だけに依存せず、24V主電源を物理的に遮断できる構成にする。

基本構成:

```text
6S LiPo x2
  |
  |-- ヒューズ
  |-- メインリレー / DCコンタクタ
  |-- 24Vメインバス
        |-- C620 x6
        |-- 24V->12V mini PC
        |-- 24V->5V 制御系
```

要件:

- 非常停止ボタンでメインリレー、またはDCコンタクタのコイル電源を落とす。
- E-stop時はC620 x6への24V供給を遮断する。
- 可能なら24V->12Vと24V->5Vも同時に遮断する。
- ただしログ保存や通信停止処理を優先する場合は、制御系5Vだけ別系統で数秒保持する設計も検討する。
- リレー/コンタクタはDC遮断定格を確認する。AC用リレーを流用しない。
- C620 x6の最大電流と突入電流を見込んで接点容量を選ぶ。
- コイルにはフライバックダイオード、またはTVSを入れる。
- 非常停止信号はTeensyにも入力し、ソフト側でも即座にモータ指令をゼロにする。

推奨動作:

1. 非常停止ボタンが押される。
2. Teensyと各ユニットMCUがモータ指令をゼロにする。
3. メインリレー/コンタクタが開く。
4. C620への24V供給が遮断される。

安全側に倒すなら、非常停止ボタンはノーマリクローズ接点を使う。配線断線時にもリレーが落ちるため、フェイルセーフになる。

### 非常停止表示灯

非常停止状態は、機体の外から一目で分かるように表示する。

要件:

- 非常停止中、メインリレーOFF、モータ電源遮断中を表示灯で示す。
- 通常動作可能、待機中、エラー中も色または点滅パターンで区別する。
- 表示灯は中央制御基板から制御する。
- 非常停止の表示はソフト状態だけでなく、可能ならリレー/コンタクタ後段の24V有無も監視して反映する。
- 視認性を優先し、機体上面または側面から見える位置に置く。

推奨表示:

| 状態 | 表示 |
|---|---|
| 非常停止中 | 赤点灯 |
| エラー | 赤点滅 |
| 待機 / 未キャリブレーション | 黄点灯 |
| キャリブレーション中 | 黄点滅 |
| 動作可能 | 緑点灯 |
| 通信断 | 青点滅または赤黄交互 |

非常停止表示灯は、GUIを見なくても安全状態が分かるため必須に近い扱いにする。

## 2-1. 中央制御基板と機体GUI

機体には小型ディスプレーを搭載し、mini PC上のGUIで起動、キャリブレーション、デバッグを行えるようにする。

### 役割

役割分担は以下。

| 要素 | 役割 |
|---|---|
| mini PC | GUI、ログ、設定編集、キャリブレーション操作、デバッグ表示 |
| Teensy | リアルタイム制御、各ユニットへの目標値配信、安全I/O、E-stop監視 |
| 各ユニットMCU | AMT22読み取り、C620制御、ステア/速度ループ |

mini PCはGUIのホストとして使う。TeensyはGUI描画を担当せず、mini PCからの指令を受けて制御系へ反映する。

中央制御基板は以下を担当する。

- Teensyを中心に、各差動ステアユニットへ目標角と目標速を送る。
- 各ユニットの状態をCANで収集する。
- 非常停止、起動許可、エラー状態を管理する。
- mini PCとの通信を行い、GUIへ状態を渡す。
- GUIからのキャリブレーション指令やStart指令を、安全条件を確認したうえで実行する。

### GUIでできること

最低限必要な画面は以下。

| 画面 | 内容 |
|---|---|
| Status | 電源電圧、CAN状態、各ユニット状態、E-stop状態 |
| Calibration | ステア原点合わせ、AMT22ゼロ点保存、ユニットID確認 |
| Start | 起動許可、モータ有効化、制御開始 |
| Debug | 各ユニットの角度、速度、モーターrpm、エラーコード表示 |
| Config | ID、CAN設定、制御パラメータ確認 |

### 操作系

候補:

| 方式 | 特徴 |
|---|---|
| mini PC + HDMI/USB小型ディスプレー | GUIを作りやすく、ログやデバッグ表示に強い |
| mini PC + タッチLCD | 単体操作しやすい。現場向き |
| mini PC + Web GUI | スマホ/ノートPCから確認しやすい |
| Teensy直結OLED | 最小構成の保険。詳細GUIには向かない |

第一段階では、mini PC上で動くGUIを本命にする。Teensy直結OLEDは、mini PCが落ちた場合でも最低限の状態だけ見たい場合の補助表示として扱う。

### GUIの起動シーケンス

```text
電源ON
  |
  |-- mini PC起動
  |-- Teensy起動
  |-- mini PC - Teensy間通信確認
  |-- 各ユニットCAN探索
  |-- ユニットID確認
  |-- AMT22通信確認
  |-- C620通信確認
  |-- E-stop状態確認
  |
  |-- 未キャリブレーションなら Calibration へ
  |-- 問題なければ Standby へ
  |-- Start 操作で Motor Enable
```

### GUIから行うキャリブレーション

最低限、以下をできるようにする。

- 各ユニットの現在角度を表示する。
- ステアを機械的な基準向きに合わせる。
- AMT22の現在値をゼロ点として保存する。
- 保存値を各ユニットMCUの不揮発メモリ、または中央制御側設定に記録する。
- キャリブレーション後に、各ユニットへゼロ点反映を指示する。

### デバッグ表示

デバッグ画面では以下を表示する。

- 各ユニットのCAN通信状態
- 各ユニットの現在ステア角
- 各ユニットの目標ステア角
- 各ユニットの駆動rpm
- 各モーターの指令rpm
- C620フィードバックの有無
- AMT22読取エラー
- E-stop入力状態
- リレー/コンタクタ状態
- バッテリ電圧
- 5V制御電圧
- 12V mini PC電圧

### 安全上の制約

- GUI上のStartだけで即モータ駆動しない。
- mini PC GUIは起動許可を要求するだけで、最終的なMotor Enable判定はTeensy側で行う。
- E-stop解除、通信正常、キャリブレーション済み、エラーなしの条件が揃ったときだけMotor Enableを許可する。
- E-stop中はGUI操作より非常停止状態を優先する。
- Debug画面から直接モーターを動かす場合は、低速・短時間・明示的な確認操作を入れる。
- mini PCが落ちた、またはTeensyとの通信が途切れた場合は、Teensy側で安全停止へ移行する。

## 3. グラウンド設計

### 原則

電位は共通、電流経路は分離する。

```text
中央分電盤のGNDバー = スターの中心
  |-- 6S LiPo (-)
  |-- 各C620の電源(-)       大電流リターン
  |-- 中央DC-DCのGND
  |-- 制御系5VのGND         基準用
```

### 理由

- 全ノードのGNDが共通でないと、CANトランシーバのコモンモード電圧許容範囲を逸脱する可能性がある。
- M3508/C620の大電流リターンが制御GNDを通ると、IRドロップでGNDが揺れる。
- GND揺れはSPI誤読、MCUリセット、CANエラーの原因になる。

### キャリアボードでの実装方針

- C620の大電流GNDと制御系GNDを、基板上で安易に共通ベタにしない。
- モータ電流経路と制御基準経路は、配線レベルで分けて中央分電盤へ戻す。
- 最終的に中央分電盤の1点で合流させる。

## 4. CAN系

### 帯域

1フレームを約125bit、CANを1Mbpsとすると、理論容量は約8000frame/s。

コマンドは `0x200` / `0x1FF` の2フレームに集約する前提。

必要フレーム数の概算:

$$
(N_{motor} + 2) \times 1000
$$

条件:

$$
(N_{motor} + 2) \times 1000 \leq 8000
$$

したがって、

$$
N_{motor} \leq 6
$$

実質的に、1Mbpsの1バスでは3ユニットが上限の目安。

前提:

- エンコーダ角をCANに載せない。
- AMT22は各ユニットMCUで読む。
- 中央へ返すステータスは間引く。
- 4ユニット以上にする場合はCANを2系統に分割する。

### 物理層

- 終端120Ωはバス両端だけに入れる。
- 中央Teensy側と、一番遠いユニット側を終端ONにする。
- 中間ユニットには終端を入れない。
- 各ユニットには120Ωとソルダージャンパを載せ、端ユニットだけONにできるようにする。
- スタブは短くする。コネクタからトランシーバまで数cm以内を目安にする。
- CANクロックは水晶前提。NUCLEO搭載クロックを使う。
- MCUのCAN_TX/CAN_RXをCAN_H/CAN_Lへ直結しない。
- 各ノードにCANトランシーバを1個置く。

### CAN ID設計

| 対象 | ID |
|---|---|
| C620フィードバック | 0x201 - 0x208 |
| C620コマンド | 0x200 / 0x1FF |
| ユニットMCUステータス | 0x300番台など |

方針:

- ユニットMCUのステータスIDはC620帯を避ける。
- ユニットIDは0Ωジャンパ列、またはピンヘッダ＋ジャンパで設定する。
- C620本体のモータIDはC620側DIPで設定する。

## 5. AMT22 / SPI系

### 電圧とレベル変換

AMT22は5Vで駆動する。MCUは3.3V系なので、SPI信号のレベル整合に注意する。

| 信号 | 方向 | 対策 |
|---|---|---|
| SCLK | MCU 3.3V -> AMT22 5V入力 | AMT22のVIH確認後、直結可否を決める |
| MOSI | MCU 3.3V -> AMT22 5V入力 | AMT22のVIH確認後、直結可否を決める |
| CS | MCU 3.3V -> AMT22 5V入力 | AMT22のVIH確認後、直結可否を決める |
| MISO / SDO | AMT22 5V出力 -> MCU 3.3V入力 | 抵抗分圧またはバッファ必須 |

MISOの抵抗分圧:

| 抵抗 | 値 |
|---|---:|
| 上側 | 1.8k |
| 下側 | 3.3k |

出力電圧:

$$
5 \times \frac{3.3}{1.8 + 3.3} = 3.24V
$$

SPI速度は2MHz程度を想定する。抵抗分圧で波形が鈍る場合は、74LVC1G125 / 74LVC1G14 などで受ける。

### SPI注意点

- AMT22はSPIライクだが、CSタイミング、ダミーバイト、チェックビット処理に注意する。
- CSはGPIOで制御する。
- MISOプルアップは基本不要。
- 配線は短くする。

### 未確定

- AMT22のVIHをデータシートで確認する。
- 3.3VがHighとして認識されるなら、SCLK/MOSI/CSは直結でよい。
- 3.3V Highが不十分なら、送信側にもバッファを入れる。

## 6. キャリアボード部品リスト

MCU周りの電源、水晶、デカップリング、BOOT0、NRSTはNUCLEOが内蔵するため、キャリアボード側には不要。

| ブロック | 部品 | パッケージ/実装 |
|---|---|---|
| CANトランシーバ | TCAN332 / SN65HVD230 | SOIC-8 |
| LDO | AMS1117-3.3 | SOT-223 |
| MISO降圧 | 1.8k / 3.3k 抵抗 | 0603以上またはリード部品 |
| CAN終端 | 120Ω + ソルダージャンパ | 手ハンダ可 |
| ID設定 | 0Ωジャンパ列 / ピンヘッダ＋ジャンパ | 手ハンダ可 |
| デカップリング | 0.1uF + 数uF | 手ハンダ可 |
| NUCLEO接続 | ピンソケット | 2.54mm |
| コネクタ | 24V / 5V / GND / CAN / C620 / AMT22 | スルーホール推奨 |

能動ICは実質、CANトランシーバとLDOのみ。

NUCLEOはソケットで抜き挿し可能にする。MCU破損時にNUCLEOだけを交換できるため、現場復旧が速い。

## 7. 開発・実装手順

### 第一段階: NUCLEO搭載キャリアボード

1. NUCLEO-G431KB単体でファームを先行完成させる。
2. AMT22 SPI読み取りを確認する。
3. C620へのCAN指令を確認する。
4. 方位ループと速度ループを実装する。
5. ソフトが固まってからキャリアボードを起こす。
6. キャリアボードに手ハンダ部品を実装する。
7. 実機でCAN、SPI、電源、GNDの問題を確認する。

CANビットタイミングはCubeMXで設定し、制御ロジックは通常コードとして管理する。

### 第二段階: 裸チップ基板

さらに小型化したくなった場合に、同じ回路をSTM32G431K系の裸チップ基板へ移植する。

第一段階の回路、ピン割当、ファーム設計を移植可能な形にしておく。

## 8. 第二段階への移行戦略

### NUCLEOが肩代わりしている回路

第二段階では以下を自作基板側に追加する。

| 機能 | 第一段階 | 第二段階で必要なもの |
|---|---|---|
| 電源デカップリング | NUCLEO内蔵 | VDD各ピンに100nF、10uFバルク |
| VDDAフィルタ | NUCLEO内蔵 | フェライトビーズ、100nF、1uF |
| リセット | NUCLEO内蔵 | NRST-GND間100nF |
| BOOT0 | NUCLEO内蔵 | 10kプルダウン、ジャンパ |
| クロック | NUCLEO搭載水晶 | 8MHz水晶、負荷容量 |
| 書き込み | オンボードST-LINK | SWD 4パッド、外部ST-LINK |

第一段階のうちに、これらを将来追加する前提でドキュメント化する。

### ピン選定

第一段階のピン割当は、NUCLEOの都合だけで決めない。

最初からSTM32G431KのAF表に従って選ぶ。

- FDCAN_TX / FDCAN_RX は、FDCANのAFが出ているピンから選ぶ。
- SPI SCLK / MISO / MOSI は、同じSPIペリフェラルで揃うピン群から選ぶ。
- CSはGPIOでよい。
- MISOは5Vトレラントピンを狙う。
- IDジャンパやステータスGPIOは、CAN/SPIの専用機能ピンを避ける。

これにより、第二段階でCubeMXのピン定義やファームのピンマクロを変更せず移行しやすくなる。

### ファーム設計

NUCLEO固有機能に依存しない。

- オンボードST-LINKに依存しない。
- NUCLEOのLEDやユーザーボタンに依存しない。
- NUCLEO固有のBOOT制御に依存しない。
- デバッグ表示はUARTまたはCANログに寄せる。
- SWDは自前パッドと外部ST-LINK前提にする。

### キャリアボード側の仕掛け

- シルク印字とネット名は、NUCLEOコネクタ番号ではなく `PAx` / `PBx` のピン名で統一する。
- KiCad上では、論理的にSTM32G431Kのピン名で配線を管理する。
- 第二段階で追加する定石部品は、未実装ランドとして置くか、少なくとも回路図メモに残す。

## 9. 未確定事項

- AMT22のVIH確認。
- 6S満充電25.2VとC620絶対最大定格の確認。
- NUCLEO-G431KBの具体的なピン割当。
- FDCAN / SPI / IDジャンパのAF制約確認。
- MISOをFTピンにできるか確認。
- 差動運動学をファーム実装へ反映。

差動運動学については、`STEER_DRIVE_RPM_FUNCTIONS.md` を参照する。

## 10. 第一段階キャリアボード レビューチェックリスト

- [ ] CAN_H/L とCANトランシーバが接続されている
- [ ] MCUのCAN_TX/CAN_RXをCAN_H/Lへ直結していない
- [ ] 終端120Ωがソルダージャンパで切替可能
- [ ] 終端ジャンパのデフォルト状態が明確
- [ ] MISOに抵抗分圧またはバッファが入っている
- [ ] SCLK/MOSI/CSの3.3V High可否をAMT22データシートで確認済み
- [ ] 制御GNDとモータGNDの大電流経路が分離されている
- [ ] LDO近傍にデカップリングがある
- [ ] CANトランシーバ近傍にデカップリングがある
- [ ] IDジャンパで必要な全IDを設定できる
- [ ] ファームが起動時にIDジャンパを読む
- [ ] 24V系コネクタの電流定格が足りている
- [ ] NUCLEOがソケットで抜き挿し可能
- [ ] シルクとネット名がチップピン名基準になっている
- [ ] 第二段階で追加する回路がドキュメント化されている

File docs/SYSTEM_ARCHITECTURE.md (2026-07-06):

# システム全体構成

## 目的

差動ステアユニットを3基搭載した移動機構を構成する。

各ユニットは、2個のM3508と1個のAMT22を持つ自己完結型モジュールとして扱う。中央制御は各ユニットへ目標角と目標速度を送り、ユニット内でモーター協調制御とステア/速度ループを閉じる。

## 基本構成

```text
mini PC
  |-- GUI
  |-- ログ
  |-- キャリブレーション操作
  |
  | USB / UART / Ethernet
  v
中央制御基板 / Teensy
  |-- E-stop監視
  |-- 起動許可
  |-- CANバス管理
  |-- 各ユニットへ目標角・目標速を配信
  |
  | COMM_A / COMM_B / VIN_CONTROL / GND_CTRL
  v
差動ステアユニット x3
  |-- ユニット基板(STM32G474自作、開発検証はNUCLEO-G474RE)
  |-- C620 x2
  |-- M3508 x2
  |-- AMT22 x1
```

## 責務分担

| レイヤー | 担当 | 責務 |
|---|---|---|
| GUI | mini PC | 表示、設定、キャリブレーション操作、ログ |
| 中央制御 | Teensy | 安全判定、各ユニットへの指令、通信管理 |
| ユニット制御 | STM32G474自作基板 | AMT22読み取り、C620制御、ステア/速度ループ |
| 電力 | 中央分電盤 | 24V、12V、5Vの分配 |
| 安全 | E-stop回路 | C620主電源の物理遮断 |

## 制御方針

- 中央Teensyは各ユニットへ目標ステア角と目標駆動速度を送る。
- 各ユニットMCUはAMT22を直接読み、ステア角ループを閉じる。
- 各ユニットMCUはユニット内部CANでC620 x2へ指令を出し、差動ステアの2モーター協調を行う。
- 中央から見たユニットは、C620を直接操作する対象ではなく、ホイール回転数とステア角度で動くCANモジュールとして扱う。
- 中央-ユニット間通信は中央CAN(C620専用CANとは別バス)とする。G474REのFDCANを2系統使う。
- エンコーダ角を中央通信へ高周期で流さない。ユニット内で閉じる。
- 中央へ返すステータスは間引く。

## 電源方針

- 6S LiPo x2を電源源とする。
- C620 x6には6S相当の24V系をそのまま分配する。
- mini PCには24Vから12Vへ降圧して供給する。
- Teensy、センサ、各ユニット制御基板には24Vから5Vへ降圧して供給する。
- 各ユニット制御基板への基本ハーネスは `CAN_H / CAN_L / VIN_CONTROL / GND` の4線とする。
- C620用24V大電流ラインは制御4線とは別に太線で分配する。

## 安全方針

- 非常停止はソフト停止だけに依存しない。
- メインリレーまたはDCコンタクタでC620 x6への24V主電源を物理遮断する。
- 非常停止状態は表示灯で外部から確認できるようにする。
- mini PC GUIは起動要求を出すだけで、最終的なMotor Enable判定はTeensyが行う。
- mini PC通信断、CAN通信断、E-stop入力、未キャリブレーション時はMotor Enableを許可しない。

## 通信方針

ユニット外部接続は `VIN_CONTROL / GND_CTRL / COMM_A / COMM_B` の4線とする。

`COMM_A/B` は物理層を抽象化した名前で、実体は中央CANのCAN_H/CAN_Lとする(2026-07-02確定)。C620 CANはユニット内部専用とし、中央CANとは電気的に独立した別バスにする。

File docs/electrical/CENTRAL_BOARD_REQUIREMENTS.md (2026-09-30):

> **2026-09-30 X402帰路決定:** `GND_CTRL`、`GND_CTRL_LED`、`GND_24V_RETURN`を3端子銅箔ネットタイ`NetTie:NetTie-3_SMD_Pad2.0mm`で中央PCB上の1箇所に結合する。X402は購入部品ではない。J403-2/Q401 source付近に配置し、コイル/LED電流を制御GNDの共通配線へ流さない。外部での重複結合とPCB帰路/DRCは未検証。

> **2026-09-29採用更新:** ユーザー承認によりX401を **D405: Alpha & Omega Semiconductor SMBJ33CA（双方向TVS）**へ置換。J402-1（ESTOP_LOOP_RETURN/COIL_POS）とJ402-2（COIL_NEG）の間へ並列。symbol=`Device:D_TVS`、footprint=`Diode_SMD:D_SMB`。型番選定・KiCad反映済み、実ハーネスでのサージ/吸収エネルギー/解放10ms以内は実測残件。X402帰路結合は未確定。

> **2026-09-29 TN686現物情報の更新:** ユーザー確認はTN686・24V・100A表記、コイル抵抗実測0.34kΩ（340Ω）、内部保護なし。24V/340Ω=約70.6mA、約1.69Wは抵抗からの計算値（温度・電圧で変化）。100Aは主接点の表記でコイル電流ではない。提示された販売仕様の解放時間は10ms未満だが、現物・外付けクランプ追加後の実測保証ではない。同ページの2.4W/4.8Wは実測抵抗と一致せず、混載仕様として区別する。旧E228/300Ωを現物の確定値として使わない。

> **2026-09-29 現物型番の追加確認:** ユーザーは本体表記を `TN686` と回答。旧記録のKILIGEN E228との同一性、コイル1.8W/300Ω/75〜80mAの適用は未照合のため、クランプ・ヒューズの確定計算にそのまま使わない。TN686の完全な銘板（末尾型式・コイル電圧・内部回路表示）を確認する。ユーザー提示のMade-in-ChinaページはWM686/TN686/RL系混載で2.4W/4.8W、TVS組込み可能との記載があるが、現物の採用仕様・保護素子内蔵を証明しない。旧記録は履歴として保持。

# 中央制御ボード(Teensy 4.1)要件

> **2026-09-23最終方針**: 専用CANは横挿しGH3（A/B/GND）。駆動/ODOMのCAN2pin案は撤回。コイルdriverは中央搭載。主接点専用監視は付けずC620 CAN応答を補助診断とする。最新の[一括発注計画](PCB_BATCH_V2_CENTRAL_PLAN.md)を優先し、本文の旧CONTACTOR_STATUS_N案は採用しない。

> **Rev.1移行注記 (2026-09-12):** 本書の既存記述はRev.A/外部5V入力案の履歴を含む。Rev.1の電源入力、USB共存、24Vアクチュエータ出力、安全方針は `CENTRAL_BOARD_REV1_CONSTITUTION.md` を最優先正本とする。基板内蔵24V→5V Buckの確定仕様は `CENTRAL_BOARD_POWER_BLOCK_REV1.md`。既存の`reference-2026-09-12/` KiCad下書きは発注対象ではない。

## 目的

Teensy 4.1を載せる中央制御ボードをKiCadで設計する。

設計方針: **本プロジェクト専用にしすぎず、後輩・後続プロジェクトで再利用できる汎用CANマスタボードにする。** CAN 2〜3系統とI2C/UART/SPI/GPIOの拡張ヘッダを持ち、安全I/O(E-stop、コンタクタ制御)だけが本プロジェクト固有の色になる。

## 役割(SYSTEM_ARCHITECTUREより)

- 駆動CANで各ユニットへ目標値配信、状態収集
- センサーCANでオドメトリ/IMU状態推定ノードを収容
- I2Cでバッテリー電圧・電流監視を収容
- E-stop監視とMotor Enable最終判定
- コンタクタコイル制御
- mini PCとのGUI通信

## Teensy 4.1の前提

| 項目 | 内容 |
|---|---|
| ロジック電圧 | 3.3V。**5VトレラントではないのでGPIOに5V以上を直接入れない** |
| CAN | FlexCAN 3系統(CAN1/CAN2/CAN3)。CAN3のみCAN FD対応。トランシーバは非搭載なので基板側に必要 |
| USB | micro USBネイティブ(USB-CDC)。mini PCとの接続に使う |
| 電源 | VIN 3.6〜5.5V。**外部5V給電とUSB接続を併用する場合、裏面のVUSB-VINパッドを必ずカットする**(切らないとPC USBと5V系が衝突する) |

全ピン割当、Teensyソケットの回路図pin番号、予約I/Oは
`TEENSY41_CENTRAL_PIN_ASSIGNMENT.md`を正本とする。

## mini PC接続(2026-07-02決定)

第一候補: **Teensyネイティブのmicro USB(USB-CDCシリアル)**。

mini PC本体はGMKtec NucBox G2を採用する(2026-07-19)。G2は常時通電12V制御系から給電し、E-stopでモータ主電源を落としてもUSB-CDC通信、GUI、ログ、故障表示を維持する。

- 追加ハードウェア不要、転送量もGUI/ログ用途に十分。
- CAN-to-USB(CANable等)をGUI主回線にする案は不採用。GUIトラフィックが安全系バスに乗る・アダプタと独自プロトコルが増えるため。
- ただしCANableはCANバスの監視・デバッグツールとして有効なので、各CANに監視可能なGHコネクタまたはテストポイントを設ける。

## CAN

| 系統 | 用途 | トランシーバ |
|---|---|---|
| CAN1 | センサーCAN(オドメトリ/IMU、Classic CAN 1Mbps) | `TCAN1051VDRQ1` |
| CAN2 | 汎用拡張/デバッグ/予備 | フットプリント実装、初期BOMはDNP可 |
| CAN3 | 駆動CAN(G474ユニットx3、CAN FD nominal 1Mbps/data 2Mbps、BRS) | `TCAN1051VDRQ1` |

Teensy 4.1でCAN FDに対応するのはCAN3だけなので、駆動ユニット用バスをCAN3へ固定する。
F405オドメトリ基板はbxCANのためCAN1側Classic 1Mbpsへ分離する。採用済み
`TCAN1051VDRQ1`はCAN FD 2Mbps対応であり、FD化によるトランシーバBOM変更はない。

要件:

- 各CANに`RC0603FR-07120RL` 120Ωと`JS102011SAQN`スライドスイッチによる終端を実装する。中央基板が物理端ならON、各バスの最遠ノードでもう1個をONにする。
- 各CANに`ESD2CAN24DBZRQ1`を実装する。
- CANコネクタはJST GH 3pin(COMM_A / COMM_B / GND)。電源コネクタと分離し、CANをデイジーチェーン接続する。
- CAN共通回路、正式型番、配置制約は`CAN_COMMON_BLOCK_PART_SELECTION.md`を正本とする。

## 安全I/O(本プロジェクト固有部分)

| 信号 | 回路 |
|---|---|
| `ESTOP_N` 入力 | E-stopスイッチのNC接点ループを監視。24V系ループを使う場合はフォトカプラまたは分圧+クランプで3.3V化。**Teensyに生の24Vを入れない** |
| `MOTOR_PWR_EN` 出力 | 所有済みリレーを介してモーター主電源系を操作する。リレー型番・コイル/入力仕様を確認後、GPIO直結不可ならMOSFET等の駆動段を設ける |
| `MOTOR_PWR_SENSE` 入力 | 24Vモータバスの有無検出。分圧(例: 100k/10k)+クランプでADCへ |
| 表示灯出力 | 赤/黄/緑(+予備1)。表示灯が24V系ならMOSFETローサイド駆動 |

E-stopのNC接点はコンタクタコイル電源ループに**ハードワイヤで直列**が主経路であり、Teensyの監視は従。ソフトが死んでもE-stopは効く構成を維持する(POWER_DISTRIBUTION_AND_ESTOP.md参照)。

- E-stopは2個とし、NC安全接点を直列接続する。監視入力は最低限ループ全体を監視し、2026-09-26確定: 個別診断・予備chは設けず、U401 LTV-817Sの1chのみとする。
- コンタクタコイル用ローサイドMOSFET、Gate pulldown、サージクランプを中央基板へ実装する。Teensy未起動時の既定状態はOFFとする。
- `MOTOR_PWR_EN`は遠隔停止にも使用する。停止指令、通信監視異常、Teensy安全状態遷移で直ちにOFFとし、停止原因をラッチする。再投入は独立した明示的な再アーム操作でのみ許可する。
- **2026-09-23確定: コンタクタ主接点の専用監視は今回実装しない。** コンタクタ補助接点入力や主接点後24Vの専用電圧監視を追加せず、駆動MCUがC620のCAN応答有無を検出し中央へ報告する補助診断を用いる。制御5Vと中央↔駆動CANはOFF後も生かす。表示は「OFF指令中・C620応答なし」とし、CAN無応答を「遮断確認済み」や溶着検出の根拠にはしない。中央との通信自体が途絶した場合はC620応答なしと混同せず「通信不明/情報期限切れ」とする。ハードNC E-stopのコイル遮断、reset/Hi-Z時OFF、明示再アームを維持。ファーム/GUI実装は別作業。
- E-stop内蔵24V LEDは中央基板のGPIOで駆動せず、`24V_CTRL`と各ボタンの独立補助接点でハードワイヤする。中央基板には必要に応じてヒューズ付き`24V_CTRL`入出力端子を設ける。
- **メインコンタクタは所有品のKILIGEN `E228`(24V DC、100A表記)を採用する(2026-07-26)。** 販売情報上の連続使用目安は50〜60Aで、24V DC負荷遮断定格を示す正式データシートは確認できていない残存リスクがある。採用にあたり以下を必須の確認手順とする:
  1. **完了(2026-07-26)**: コイル仕様(定格コイル電圧24V DC、コイル電力1.8W、コイル抵抗300Ω、動作電圧14〜16V、解放電圧6〜8V、最大印加電圧28V DC)を確認済み。計算上のコイル電流は約75〜80mA @ 24Vで、コイル抵抗・電力表記は相互に整合する。この電流値でコイルドライバのMOSFET・ゲート抵抗を設計してよい。
  2. **実績確認済み(2026-07-26)**: 前回ロボコン機体で最大約2000W(24V換算で約83A)の負荷がかかった状態でこの個体(KILIGEN `E228`)による遮断(E-stop等での通電中の切断)に成功した実績があることをユーザーが確認した。販売情報上の連続使用目安50〜60Aを上回る電流での負荷遮断実績であり、正式なDC遮断定格の代替根拠として扱う。今回の想定最大電流がこの実績値(約83A)を明確に超えないことを設計時に確認する。
  3. 実績(2で確認した通電遮断実績)により、フル再検証キャンペーンは不要と判断する。ただし再利用前に主接点の摩耗・ピッティングの目視検査を1回行う。異常があれば再選定に切り替える。

### `ESTOP_CTRL`専用ポート

中央基板に、2個のE-stopを載せる操作パネルハーネス用の専用ポートを1個設ける。CAN、汎用GPIO、モータ電源とは共用しない。暫定4pin割当は次の通り。

| pin | 信号 | 用途 |
|---:|---|---|
| 1 | `ESTOP_LOOP_OUT` | 専用ヒューズ後の24VをNC安全接点直列ループへ送る |
| 2 | `ESTOP_LOOP_RETURN` | E-stop 1/2のNC接点を直列に通過した戻り。コンタクタコイル経路へ接続 |
| 3 | `ESTOP_LED_24V` | ボタン内蔵LED・補助接点用。安全ループとは別に保護した`24V_CTRL` |
| 4 | `GND_CTRL` | 24V LEDおよび診断入力の帰路 |

- コネクタを抜く、ケーブルが断線する、どちらかのNC接点が開く、のいずれでも`ESTOP_LOOP_RETURN`が消失してコンタクタを解放する。
- pin 1/2の安全ループはTeensyやファームを経由させない。Teensyは絶縁または保護された監視入力から状態を読むだけとする。
- pin 3のLED/補助回路短絡で安全ループ用24Vが失われないよう、pin 1系統とはヒューズまたは電流制限を分ける。
- ボタン補助接点の個別診断配線は設けない。ループ全体の監視を維持する。
- コネクタ形式はキー付き・ロック付き、定格60V以上を条件とし、正式型番と許容電流は採用コンタクタの24Vコイル電流確定後に決める。

## 外部状態表示LED

- 独立した安全表示灯用に赤/黄/緑(+予備)の24V対応ローサイド出力を設ける。
- テープLEDは独立CANノード基板で制御する。中央基板から5Vレベル変換済みDATA線を直接引き出す案は不採用とし、拡張CANへ接続する。
- 中央TeensyはLEDノードへモード、色、明るさ、速度、バッテリー状態、故障状態などの高位コマンドを送る。全ピクセルのRGB値を毎フレームCAN送信せず、アニメーション波形はLEDノード側で生成する。
- LEDノードはCANタイムアウト時に通信異常表示へ遷移し、受信した古い走行状態を無期限に表示し続けない。LED表示自体は安全機能として扱わない。
- 24V RGBテープを採用する場合は、各色の負荷電流に合わせた外付けMOSFETドライバを使う。
- LED用電源分岐は個別ヒューズとし、最大電流をコネクタおよびシルクへ明記する。

## 将来24V電磁弁・補助負荷の分離方針(2026-07-20確定、2026-09-12撤回)

**この節は`CENTRAL_BOARD_REV1_CONSTITUTION.md`の「24V負荷制御」により撤回された。** 中央基板に汎用N-MOSローサイド出力を数ch搭載する方針に変更済み。旧方針は経緯として残す。

- (旧)Rev.A中央基板に汎用24V負荷出力を増設しない。中央基板はロジック、CAN、E-stop監視、メインコンタクタ制御、24V状態監視を担当する。
- 将来の電磁弁、リレー、24V表示灯などは、別の24V出力ドライバ基板に分離する。この基板にMOSFET、フライバック/TVS、ヒューズ、必要なら電流・断線診断を持たせる。
- 中央基板と外部ドライバ基板はCANとハードウェア許可信号`AUX_OUTPUT_EN`で接続する。`AUX_OUTPUT_EN` GPIOはTeensyピン割当時に1本予約する。
- 24V負荷電流は中央PCBを経由させず、24V分電点から個別ヒューズ経由で外部ドライバ基板へ直接給電する。

## 再利用性のための拡張ヘッダ

外部コネクタはJST GHを基本とし、シルクに信号名を明記する。

| 拡張 | 数 | 備考 |
|---|---|---|
| I2C | 2系統(Wire/Wire1) | 1系統をバッテリー電圧・電流監視に使用。プルアップ抵抗のフットプリント付き(ジャンパで切離し可) |
| UART | 2系統 | TX/RX/GND |
| SPI | 1系統 | CS用GPIO 2本付き |
| GPIO/ADC | 8本程度 | 3.3Vロジック注意のシルク表記 |
| 電源出力 | 5V / 3.3V / GND | 拡張デバイス給電用(合計電流に上限表記) |

### 拡張ヘッダ保護・表示(2026-09-12確定)

汎用CANマスタボードとして後輩・後続プロジェクトが雑に配線する前提を置き、外部GHへ出る全信号にESD/TVS保護を入れる。

- **ESD/TVS**: `SRV05-4`(SOT-23-6、4ch低容量TVSアレイ)を全拡張ヘッダへ適用する。I2C(SDA/SCL x2系統=4本)で1個、UART(TX/RX x2系統=4本)で1個、SPI(CS0/CS1/MOSI/MISO/SCK=5本)で2個(4ch+1ch)、GPIO/ADC(8本)で2個(4ch+4ch)、計6個を同一部品番号で使う。VRWM=5V min、Cj typ 1.5pF(I/O-GND)、VF max 1.2V、クランプ電圧12.5〜17.5V(Littelfuse/Bourns/Semtech/onsemi等の複数社セカンドソースあり、SOT-23-6で全チャンネル共通)。3.3Vロジックへ使うためpin5(VCC/steeringレール)は`+3V3_TEENSY`、pin2(GND)は`GND_CTRL`へ接続する(5V USB系ではなく3.3Vへ吊ることで通常のHIGHレベルで導通しない)。
- **アクティビティLED**: 追加のTeensy GPIOは消費しない。CAN TXD/RXD、UART TX/RX、SPI SCKなど既存の信号ネットへ直接タップし、小信号トランジスタ(digital transistor、例: ベース抵抗内蔵SOT-23品)でLEDをバッファ駆動する。Rev.Aで予備としているTeensy pin 33/37/38/39は消費しない。
- 具体的な部品番号(digital transistor)と在庫・価格は発注時に別途確定する。

## 電源

- 入力: 購入済み24V→5V/5A DC-DCから5V。主入力コネクタはXT30等の5A対応品。
- 中央基板上でTeensy、G474ユニットx3、F405オドメトリ/IMU基板へ5V/GNDをスター分配する。MCUノード4枝は`1206L050/15YR`で個別保護し、PPTC後に`LTST-C190KGKT`+1.5kΩの電源表示を設ける。2026-09-26ユーザー指定で駆動3枝のTP211〜TP213は省略し、電圧はJ201〜J203で実測する。ODOM枝TP214は維持。Teensy/拡張枝は負荷実測後に別定格を選定する。
- Teensy VINへ5V直結。3.3VはTeensy内蔵レギュレータ(外部負荷は250mA程度まで)。拡張デバイスの3.3V消費が増える場合は基板に3.3V LDOを追加。
- 5A主入力はAMASS `XT30PW-M`からTI `TPS259470LRPWR`へ入力し、逆流、突入、過電流、過熱、逆極性を保護する(2026-08-04確定、2026-09-12具体化)。`RILM=750Ω`のtyp 4.45Aを初期値とする。SD-25B-5を5.00Vへ調整・封印し、UVLO/OVLOは1% `732k/51.1k/221k`でtyp 4.43V/5.46Vに設定する。連続5Aに使えないLM66100や別series diodeは追加しない。2mm角QFNは4層GND copperとthermal viaを必須とする。
- Teensy枝は`1206L075/16WR`、拡張5V枝は`1206L050/15YR`を初期値とする。Teensy 3.3Vから外部へ供給する合計はRev.Aで100mA以下とする。

### USB給電のdiode-OR化(2026-09-12確定)

- Teensy裏面のVUSB-VINパッドは従来通りカットする(システム5VとUSB 5Vの直結衝突を避けるため)。
- カットした上で、`+5V_SYS`(保護後)とTeensyのVUSBパッドの両方から、それぞれ独立したSchottkyダイオードを介してVINへ供給するdiode-OR回路を追加する。システム電源が無い状態でもUSB単体でTeensyが起動でき、ベンチでのファーム書き込み・デバッグにシステム24V投入が不要になる。
- ダイオードは1A級・低VF・SOD-123/SOT-23系の小信号Schottkyを想定する(候補: Nexperia PMEGシリーズ等)。正式な型番・在庫は発注時に確定する(候補調査時点でDigiKeyの`PMEG4010CEH,115`は欠品だったため、この型番はそのまま採用しない)。

### USB→+5V_SYS給電(2026-09-26追加)

- USBだけでCAN試験とノード1基分の5V給電ができるよう、Teensy VUSBから第2 eFuse `TPS259470ARPWR`(auto-retry)を通して`+5V_SYS`へ給電する。ILIMは`RILM=3.32kΩ`で0.85/1.007/1.15A(TPS25947 DS表)。
- 外部5Vが来たらU102のOVLOを`+5V_RAW`分圧で持ち上げて出力OFFにし、外部5Vを優先する。両eFuseのtrue RCBでUSBと外部5Vの間に逆流は生じない。
- 接続表・定数は`CENTRAL_BOARD_REV1_KICAD_ENTRY_REFERENCE.md` 3.1節を正本とする。

## 部品リスト(主要)

| ブロック | 部品 | 備考 |
|---|---|---|
| MCUボード | Teensy 4.1(ピンソケット実装) | 抜き差し交換可能に |
| Teensyソケット | Sullins `PPPC241LFBN-RC`または`PPTC241LFBN-RC` x2 | PJRC推奨1x24、2.54mm pitch、列中心間15.24mm。Teensy側header候補はAmphenol `68000-224HLF` |
| 5V主入力 | AMASS `XT30PW-M` | 横向きTHT、連続15A定格 |
| 5V主保護 | TI `TPS259470LRPWR` | 5.5A級eFuse、true RCB、latch-off |
| CAN | `TCAN1051VDRQ1`、駆動用x1、センサー用x1、汎用x1(DNP可) | SOIC-8、5V VCC/3.3V VIO |
| CAN保護 | `ESD2CAN24DBZRQ1` | SOT-23 |
| CAN終端 | `RC0603FR-07120RL` + `JS102011SAQN` | 120Ω + スライドスイッチ |
| コイルドライバ | `IRLML0100TRPBF` + diode/TVS clamp | 100V Nch SOT-23、Gate 100Ω/47kΩ pulldown。3.3V駆動とcoil解放時間を実測。1N4007単独clampは初期案にしない |
| E-stop入力 | `LTV-817S` | 1ch、直列NCループ全体だけを監視 |
| E-stop操作パネル | `ESTOP_CTRL` 6pin x1 | NC直列ループ往復、独立LED電源/GND、補助接点x2。抜去時停止 |
| E-stop connector | Molex `43650-0600` / `43645-0600` | Micro-Fit 3.0 single-row 6pin mating pair。`43025-0600`はdual-row housingで嵌合しない |
| 24Vセンス | 分圧抵抗 + クランプダイオード | ADC入力 |
| バッテリー監視 | 購入済みMatek `I2C-INA-BM` 外部モジュール | INA228/INA238系、内蔵200uΩシャント。主電流は中央PCBへ通さず、モジュールを主電源正側へ直列配置。I2CはGH4（G/SDA/SCL/5V）で接続 |
| コネクタ | GH(CAN/分岐電源)、XT30等(5V主入力) | CANと電源を別コネクタにする |
| G474枝保護 | `1206L050/15YR` x4 | 20℃ Ihold 0.50A。高温deratingと突入を実測確認 |
| 5V分岐 | `SM02B-GHS-TB` + `GHR-02V-S` | 横挿しGH2、1=5V、2=GND、AWG26 |
| 枝LED | `LTST-C190KGKT` + `RC0603FR-071K5L` | PPTC後の5V存在表示。ノード正常表示ではない |
| 拡張ヘッダTVS | `SRV05-4`(SOT-23-6) x6 | I2C/UART/SPI/GPIO全ヘッダ共通。pin5=`+3V3_TEENSY`、pin2=`GND_CTRL` |
| USB diode-OR | Nexperia `PMEG2010EA,115` x2 | `+5V_SYS`側・VUSB側からそれぞれVINへ(回路図リファレンスで型番指定済み) |
| USB→5V_SYS | TI `TPS259470ARPWR` | USB側eFuse。auto-retry、ILIM≈1A。主入力と同じRPWパッケージ |

## チェック項目

- [ ] VUSB-VINパッドカットを組立手順に明記した(diode-OR追加後も維持)
- [ ] USB単体接続時とシステム5V単体時、両方でTeensyが起動することを確認した
- [ ] USB単体でCAN通信とノード1基の起動ができ、2基目追加でU102が電流制限することを確認した
- [ ] USB接続中に外部5Vを抜き差ししてもTeensyのUSB接続が切れないことを確認した
- [ ] 拡張ヘッダ(I2C/UART/SPI/GPIO)全信号にTVSアレイが入っている
- [ ] Teensyに5V以上が入る経路がない(E-stop、SENSE、表示灯)
- [ ] 中央CAN終端がボード上にあり、`TERM ON/OFF`スライドスイッチで切れる
- [ ] バス監視用の分岐コネクタがある
- [ ] 拡張ヘッダのシルクに信号名と3.3V注意がある
- [ ] コネクタピン配置がユニット基板と統一されている

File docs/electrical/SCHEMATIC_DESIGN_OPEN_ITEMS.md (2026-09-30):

> **2026-09-30 X402更新:** 現行`hardware/central-board/central-board/safety-1.kicad_sch`のX402を3端子銅箔ネットタイ（`NetTie:NetTie-3_SMD_Pad2.0mm`）として選定・footprint割当済み。3帰路をPCB上の1点で結合する。PCBへの配置・配線、外部重複結合の確認、DRCは残件。以下のX402=TBDは旧履歴。

> **2026-09-29採用更新:** ユーザー承認によりX401を **D405: Alpha & Omega Semiconductor SMBJ33CA（双方向TVS）**へ置換。J402-1（ESTOP_LOOP_RETURN/COIL_POS）とJ402-2（COIL_NEG）の間へ並列。symbol=`Device:D_TVS`、footprint=`Diode_SMD:D_SMB`。型番選定・KiCad反映済み、実ハーネスでのサージ/吸収エネルギー/解放10ms以内は実測残件。X402帰路結合は未確定。

> **中央 2026-09-29:** 電源/CAN以外をKiCadへ配線。F402=LED枝保護TBD、X401=コイルクランプTBD、X402=帰路結合TBD（3ネット間の導通なし）として可視化。部品選定/帰路確定が完了した意味ではない。[詳細と残件](CENTRAL_NONPOWER_WIRING_2026-09-29.md)。

# 回路設計 未確定事項・着手順

## 目的

中央Teensy基板、差動ステアユニット基板、オドメトリ基板のKiCad回路図を作る前に、未確定事項と決定順を固定する。

回路ブロック、部品調査、ERC、配置配線制約の整理はAI支援で行う。PCB上の最終配置・配線は人がKiCad GUIで行い、各ブロックの制約表を基にチャットで逐次レビューする。

## 優先度

| 優先度 | 意味 |
|---|---|
| P0 | 決まらないと回路ブロックまたはコネクタ仕様を確定できない |
| P1 | 仮回路を作れるが、PCB配置開始前に確定が必要 |
| P2 | 回路図作成と並行可能。PCB外形・配置・製造前までに確定する |

## 共通部品選定基準

候補部品は次の順序ではなく、全項目を比較表にして総合評価する。

| 評価軸 | 確認内容 |
|---|---|
| 入手性 | DigiKey/Mouser/LCSC等の正規流通在庫、複数調達先、Active状態、代替候補 |
| 価格 | 試作5～10台相当の少量単価、最小発注数、送料を除く実装単価 |
| 採用実績 | メーカー評価基板、複数の公開回路・実働プロジェクトでの使用例。コピー数ではなく独立した設計例を確認 |
| 信頼性 | データシート定格、保護機能、温度範囲、ディレーティング、メーカー品質情報 |
| 実装性 | ステンシル＋リフローでの実装余裕、ピッチ、露出パッド、部品方向、AOI/目視検査性 |
| 修理性 | ホットエア/はんだごてでの交換性、ピンへのアクセス、代替部品とのフットプリント互換性 |

Rev.Aは受動部品0603以上、LQFP/SOIC/TSSOP/SOT系ICを優先する。BGA/WLCSP、0201以下は原則不採用。QFN/DFNや露出パッド品は、性能・入手性・基板面積上の利点が明確で、推奨ステンシル開口とサーマルビア条件をデータシートから設定できる場合だけ採用する。

## 最初に解消する文書間不整合(P0)

| ID | 未確定/不整合 | 影響 | 決定・確認方法 |
|---|---|---|---|
| DOC-01 | ~~ユニット要件と製作計画に旧`JST XH`、電源+CAN一体4線が残る~~ | 全基板コネクタ、共通CANブロック | **解消(2026-07-20): AMT22中継を横挿しGH 6pin `SM06B-GHS-TB`へ、製作計画の旧4線コネクタ記述をGH 2pin電源+GH 3pin CAN x2(渡り)へ更新。docs/electricalから旧XH/一体4線記述を除去済み** |
| DOC-02 | ~~SWDが2.54mm/Tag-Connect記載とSTDC14確定事項で不一致~~ | G474共通最小構成 | **解消(2026-07-19): ロボット側をGH 6pinへ統一し、WeAct MiniDebugger側SH 10pinとの専用変換ケーブルを使う** |
| DOC-03 | ~~`can_interface`共通ブロックの旧定義が4pin(COMM_A/B/5V/GND)~~ | 共通階層シート | **解消(2026-07-20): 製作計画の`can_interface`定義は横挿しGH 3pin x2(COMM_A/B/GND)+電源別GH 2pinへ更新済み。旧4pin定義は正本から消滅** |
| DOC-04 | ~~中央CAN3をCAN FD化するか、初版は全バスClassic CAN 1Mbpsにするか未確定~~ | 中央・ユニットCANトランシーバ | **更新(2026-07-31): Teensy CAN3-G474 x3の駆動中央バスをCAN FD nominal 1Mbps/data 2Mbps+BRSとする。F405センサーCANとC620 CANはClassic 1Mbpsを維持。`TCAN1051VDRQ1`はCAN FD 2Mbps対応のためBOM変更なし** |

## 全基板共通ブロック

| ID | 優先度 | 未確定事項 | 影響基板 | 決定・確認方法 |
|---|---|---|---|---|
| COM-01 | P0 | **回路図段階解消(2026-07-19): `ECS-80-8-33Q-JES-TR`、C0G 10pF x2を初期実装** | ユニット、オドメトリ | 8MHz、CL=8pF、ESR max 500Ω、±20ppm、−40～125℃。部品は共通化し、G474/F405各実基板で8.2/10/12pFを評価して最終調整。詳細は`STM32G474_MINIMUM_CIRCUIT_PART_SELECTION.md`と`STM32F405_ODOMETRY_PIN_ASSIGNMENT.md` |
| COM-02 | P2 | **上挿し`BM06B-GHS-TBT`、ラッチ側を基板内側に確定。** 1番を向ける基板方向のみ未確定 | ユニット、オドメトリ | `GHR-06V-S`+`SSHL-002T-P0.2`。配列は1=GND、2=SWCLK、3=SWDIO、4=NRST、5=DBG_TX、6=DBG_RX。配置時にシルクの1番表示とケーブル引出方向を確定する |
| COM-03 | P0 | **解消(2026-07-19): `TCAN1051VDRQ1`採用、`TJA1051T/3`代替候補** | 全基板 | VCC=5V、VIO=3.3V、SOIC-8、バスフォルト±58V。詳細は`CAN_COMMON_BLOCK_PART_SELECTION.md` |
| COM-04 | P0 | **解消(2026-07-19): `ESD2CAN24DBZRQ1`採用** | 全基板 | SOT-23、2ch双方向、±24V working。旧PESD1CAN-UはNot for Design Inのため不採用 |
| COM-05 | P0 | **解消(2026-07-19、2026-09-06部品更新): `TLV76133DCYR`、入出力各100nF+10uF X7Rを採用** | ユニット、オドメトリ | SOT-223のVOUTタブへ放熱銅箔を設け、実負荷で温度確認。詳細は`POWER_5V_COMMON_BLOCK_PART_SELECTION.md` |
| COM-06 | P0 | **解消(2026-08-04): MCUノード=`LM66100DCKR`、中央5A主入力=`TPS259470LRPWR`** | 全基板 | 中央入力逆接は別の60V級series保護が必要。eFuse UVLO/OVLOはworst-case計算後に抵抗値を確定する |
| COM-07 | P1 | **ユニット基板のみ解消(2026-07-19): 分圧、10nF、上下クランプをPA0へ接続** (分圧は2026-09-21にR13=22kΩ/R14=10kΩ=0.3125倍へ変更、クランプは`BAT54S-HF`) | ユニット | 5Vを0.3125倍。長いADC sample timeと基板別校正を使う。F405オドメトリRev.AはPA0をTIM2_CH1へ使うため5V監視ADCを非実装。詳細は各基板要件 |
| COM-08 | P1 | **MCUノード側解消(2026-07-19、F405流用2026-07-25): Lite-On C190シリーズ緑/黄/赤、各1kΩ** | 全基板 | PWR/RUN=`LTST-C190KGKT`、COMM=`LTST-C190KSKT`、ERR=`LTST-C190KRKT`。中央基板固有LEDは別途決定 |
| COM-09 | P1 | **解消(2026-07-19): CAN=`SM03B-GHS-TB`、5V=`SM02B-GHS-TB`。ハウジングは各極数の`GHR`、端子`SSHL-002T-P0.2`** | 全基板 | 常設電源/CANは横挿し・AWG26を原則とし、デバッグGH 6pinだけ上挿し |
| COM-10 | P1 | **解消(2026-07-19): 終端スイッチ`JS102011SAQN`、抵抗`RC0603FR-07120RL`** | 全基板 | SPDTのCommonと片側throwを使用し、`TERM ON/OFF`をシルク表示する |
| COM-11 | P2 | **G474主要ネットは`S1751-46R`、高密度信号は1.0～1.5mm露出銅padに確定** | 全基板 | 主要電源/CAN/Reset/BOOT/SWOはフック対応SMT loop。中央基板の必要個数は回路図作成時に確定 |

## 差動ステアユニット基板

| ID | 優先度 | 未確定事項 | 決定・確認方法 |
|---|---|---|---|
| UNIT-01 | P0 | C620側CANコネクタの正式型番・ピン順、C620内部終端の有無 | C620実機、純正ケーブル、公式資料を確認しテスタで終端抵抗を測定 |
| UNIT-02 | P0 | AMT222A側Pico-Lockから基板側GHへ接続するハーネス構成とピン順 | AMT-06C-1-036現物/公式資料を基にストレートまたは変換ハーネスを確定 |
| UNIT-03 | P1 | ~~UNIT_IDを3bit DIP、ジャンパ、Flash設定のどれにするか~~ | **解消(2026-07-20): 3bit DIPスイッチ(PC6-8、内部プルアップ、ON=GND)に確定。起動時RUN LEDのID回数点滅で目視確認、全OFFは未設定エラー。DIP型番は部品選定で確定** |
| UNIT-04 | P1 | C620 CAN終端の実装値/DNP既定 | C620 x2と基板を接続した状態で電源OFF時のCAN_H-L合成抵抗を測る |
| UNIT-05 | P1 | AMT22 SPI各線の直列抵抗実装値/DNP | 配線長と立上りを見て22〜100Ωのフットプリントを設け、実測で確定 |
| UNIT-06 | P1 | 24Vローカル降圧予備フットプリントをRev.Aへ残すか | 5Vハーネス電圧降下の実測結果で判断 |
| UNIT-07 | P2 | 基板外形、取付穴、コネクタの向き、AMT22/C620までの最大ケーブル長 | CAD上の取付空間とサービス方向から決定 |

## オドメトリ基板

| ID | 優先度 | 未確定事項 | 決定・確認方法 |
|---|---|---|---|
| ODOM-01 | P0 | **解消(2026-07-20): `AMT102-V`インクリメンタル x3、GH4は1=5V/2=GND/3=A/4=B、Z相なし** | 現物ハーネスの線色と嵌合面視ピン番号は製作時に再照合 |
| ODOM-02 | P0 | **解消(2026-07-20): `SN74LVC2G17DBVR` x3、3.3V給電、5.5V tolerant Schmitt入力でA/B 6chを受ける** | 各ICに100nF。直列R/ESD/RCはODOM-05で最終確定 |
| ODOM-03 | P0 | **解消(2026-07-25): 購入済み`ICM-42688-P` 8pinブレークアウト x1を3.3V給電・SPI3接続で剛結する** | 信号順はVCC/GND/AD0(MISO)/SDA(MOSI)/SCL(SCLK)/CS/INT1/INT2。物理pin 1、pitch、外形、固定穴は到着後に実測 |
| ODOM-04 | P1 | AMT102のDIP分解能と`countsPerRev`既定値 | 最大輪速時の入力周波数と精度を計算して決定 |
| ODOM-05 | P1 | **解消(2026-07-25): `ESDS452DBZR` x3をコネクタ直近へ置き、A/B各線へ100Ω初期値の直列抵抗。順序はconnector -> TVS -> R -> Schmitt buffer -> MCU** | RCはDNP footprintのみ用意し、最大周波数と実測波形から必要時に実装 |
| ODOM-06 | P1 | ~~unitId=4を固定配線、DIP、Flashのどれで与えるか~~ | **解消(2026-07-20): ユニット基板と共通の3bit DIPスイッチ(PC6-8)をunitId=4に設定。回路ブロックを完全共通化し、起動時RUN LED点滅で誤設定を目視検出** |
| ODOM-07 | P1 | **解消(2026-07-20): Rev.Aは5V監視ADCを非実装。PC0への移設も行わない** | PA0/PA1はTIM2エンコーダ入力に専用 |
| ODOM-08 | P2 | IMU座標軸、基板取付向き、中心からのオフセット許容 | 機体CADと状態推定座標系を合わせ、シルクへXYZを表示 |
| ODOM-09 | P2 | 基板外形、取付穴、AMT102コネクタ方向 | 測定輪ハーネスと振動源から決定 |

## Teensy中央基板

| ID | 優先度 | 未確定事項 | 決定・確認方法 |
|---|---|---|---|
| CTR-01 | P0 | **解消(2026-08-04): `TEENSY41_CENTRAL_PIN_ASSIGNMENT.md`へCAN1/2/3、安全I/O、ADC、I2C、SPI、UART、LEDを固定** | PJRC公式pinout Rev.3/4と照合済み。CAN3=pin 30/31 |
| CTR-02 | P0 | **解消(2026-08-04): PJRC推奨Sullins `PPPC241LFBN-RC`/`PPTC241LFBN-RC` x2、Teensy側header候補`68000-224HLF`、列中心間15.24mm** | Teensy直下を全面keepoutとし、micro USB、Program button、microSDのサービス空間をPCBで確認する |
| CTR-03 | P0 | **解消(2026-07-26): KILIGEN E228を実績根拠付きで採用、24V/75〜80mA coil** | 再使用前に接点の摩耗・ピッティングを目視確認する |
| CTR-04 | P0 | **回路方式解消(2026-08-04): `IRLML0100TRPBF`、Gate 100Ω、47kΩ pulldown、diode+TVS clamp** | 3.3V gate駆動、Q1 VDS、coil解放時間を実測してTVS定格を確定する。1N4007単独clampは初期案にしない |
| CTR-05 | P0 | **回路方式解消(2026-08-04): `LTV-847S` 4ch、各入力2.2kΩ x2で直列loop・補助接点x2を絶縁監視** | 約5mA入力で全温度のLow levelと抵抗損失を実測する |
| CTR-06 | P0 | **回路側解消(2026-08-04): `INA238AIDGSR`＋外付け100A/75mV Kelvin shunt。主電流はPCBへ流さない** | 外付けshunt正式型番だけ機械取付寸法確認後に確定する |
| CTR-07 | P0 | **解消(2026-08-04): MCU4枝=`1206L050/15YR`、Teensy=`1206L075/16WR`、拡張=`1206L050/15YR`初期値** | 高温・突入・短絡試験で最終確認する |
| CTR-08 | P0 | **部品解消(2026-08-04): 5V主入力=`XT30PW-M`、主保護=`TPS259470LRPWR`、枝=`SM02B-GHS-TB`** | XT30極性/footprintを二重照合し、UVLO/OVLOをrail/comparator/resistor worst-caseで確定する |
| CTR-09 | P1 | **回路値解消(2026-08-04): 100kΩ+100kΩ/20kΩの1/11、各0.1%、1kΩ+10nF+3.3V clamp** | 40V印加試験と実測校正で判定閾値を確定する |
| CTR-10 | P1 | E-stop内蔵LEDの点灯条件とボタンのNO補助接点有無 | 常時/押下時/モータ遮断時から運用を確定し現物接点を確認 |
| CTR-11 | P1 | 24V安全表示灯の型番、電流、MOSFET出力数 | 赤黄緑+予備の負荷仕様を決める |
| CTR-12 | P1 | テープLEDの方式、電圧、長さ、電力 | Rev.Aでは外付けドライバI/O予約を基本とし、方式確定後に別回路化 |
| CTR-13 | P1 | **解消(2026-08-04): Rev.Aは外部3.3V LDOなし、拡張3.3V合計100mA上限** | 実測でTeensy温度と3.3V railを確認する |
| CTR-14 | P1 | **解消(2026-08-04): Program外出しなし。Teensy本体buttonとmicro USBへ直接アクセス** | PCB配置でサービスkeepoutを確認する |
| CTR-15 | P1 | **解消(2026-08-04): GUI要求に加えて物理`REARM_SW_N`押下を必須化** | ファーム安全状態遷移へ反映する |
| CTR-16 | P0 | **再検討中(2026-08-05): 通信・汎用I/O数は未確定。** 旧案はI2C x2、UART x2、SPI x1(CS x2)、GPIO/ADC x8だったが、専用機能を優先しつつ過度にならない汎用性へ整理し直す | 下記CTR-21〜25を対話で確定後、pin assignmentとschematic referenceを同時更新する。現回路図へはまだ反映しない |
| CTR-17 | P2 | 基板外形、取付穴、NucBox上部への積層高さと吸気/Wi-Fiアンテナ空間 | 機体CAD上でサービスデッキを設計 |
| CTR-18 | P0 | 24V control inputのreverse/surge保護部品、fuse値、TVS定格 | 24V source transientとharness条件を定義して60V級series保護を選定する |
| CTR-19 | P0 | 外付けshunt sense 2線のsource-end fuse/fusible resistor | battery側取付位置、定格、service方法を分電盤設計と同時に確定する |
| CTR-20 | P1 | 物理rearm switchをboard-localにするかoperator panelへ置くか | 操作性と誤投入riskを機体layoutで比較し、片方だけ実装する |
| CTR-21 | P0 | **CAN物理コネクタ数を再検討中。** 候補はCAN1/2/3各1個、合計GH3 x3。旧案の各バスIN/OUT x2（合計6個）は過剰の可能性 | 中央基板を各バス端点とし、デイジーチェーンは下流node側で行えるか、CANable等のservice接続方法も含めて確定する |
| CTR-22 | P0 | **外部通信・GPIO構成を再検討中。** 候補はI2C x2、UART x1、USB-CDC x1、GPIO/ADC 8本。SPI外出し、UART x2維持、GPIO本数は未確定 | GPIOは先行基板の「電源/GND/IO x2」単位を参考に、GH4 x4（1=VCC、2=GND、3/4=IO、IOは3.3V専用）を候補とする。**2026-09-26確定: GPIOの電源ピンは列全体でジャンパ1個(JP505)により3.3V/5V切替、IOは3.3Vのまま**(`CENTRAL_BOARD_REV1_KICAD_ENTRY_REFERENCE.md` S05)。IO LEDはADC負荷になるため不採用またはDNP、各IOは100ohm、ESD、pull-up/down/ADC-CのDNP footprintを検討する |
| CTR-23 | P0 | **バッテリーA/Bへ付ける市販I2C電圧・電流sensor x2の型番、address、給電、測定位置が未確定。** 現在のINA238＋外付けshunt案を置換するか併用するかも未確定 | 現物型番とdatasheetを確認し、同一address時はI2C0/I2C1分離またはmuxを比較する。確定までINA238回路を削除しない |
| CTR-24 | P0 | **コンタクタ後モータbusの監視と回生chopperは方式検討中。** 必須候補はload側bus電圧監視、analog comparatorによる自律chopper、外付けaluminum resistor、power MOSFET。load側bus電流sensorとchopper電流sensorは必須か未確定 | Chopperはmain fuse/contactorのC620側へ接続し、Teensy/I2C停止中もbus電圧で動作させる。Teensyは`MOTOR_PWR_SENSE`、`BRAKE_ACTIVE`、`BRAKE_FAULT_N`等の監視に限定する案を、停止energy、resistor pulse rating、fuse位置から評価する |
| CTR-25 | P1 | 部室在庫`BM14270AMUV-LBE2`をbusbar非接触電流監視へ使う案、およびchopper抵抗電流に既製sensor moduleを使う案は未確定 | BM14270はI2C magnetic sensorのためbusbar形状・距離・飽和・周辺磁界を含む実装後校正が必要。chopper用moduleは型番、双方向range、bandwidth、出力方式を確認してから接続先を決める |

## PCB外の電源・将来拡張

| ID | 優先度 | 未確定事項 | 回路図への扱い |
|---|---|---|---|
| SYS-01 | P0 | Rev.Aに将来48V上半身系をどこまで含めるか | 推奨は中央基板に`UPPER_PWR_EN`、電圧センス、外付けドライバ用I/Oだけ予約し、大電力回路は載せない |
| SYS-02 | P1 | LiPo並列の理想ダイオード/逆流防止モジュール | 中央PCB外の分電盤として別設計 |
| SYS-03 | P1 | 主ヒューズ・各LiPoヒューズ最終値 | 実走電流測定後に確定。回路図には定格欄を設ける |
| SYS-04 | P1 | NucBox G2現物の入力定格と専用USB-Cケーブル結線 | 付属アダプタ銘板と実機負荷試験で確定 |
| SYS-05 | P2 | 将来QDDの回生吸収、48V放電、落下対策 | QDD型番・個数・機構確定後に独立電源基板として設計 |
| SYS-06 | P1 | **解消(2026-07-20): 電磁弁等の汎用24V出力は中央PCBに載せず、CAN+`AUX_OUTPUT_EN`で接続する独立ドライバ基板に分離** | 中央基板は`AUX_OUTPUT_EN` GPIOと拡張CANを予約。24V負荷電流は中央PCBを経由させない |

## 回路ブロック作成順

### フェーズA: 設計入力の固定

1. DOC-01〜04の文書不整合を解消する。
2. GHの正式コネクタ型番と、WeAct MiniDebugger 10極ポートのコネクタシリーズ・ピッチ・1番方向を決める。
3. G474、Teensyのピンマップを固定する。
4. Rev.Aの範囲を固定し、将来48V系は予約I/Oに留めるか決める。

### フェーズB: 公式資料調査と共通部品確定

1. G474最小構成、水晶、STDC14。
2. 5V入力保護、3.3V LDO。
3. CANトランシーバ、TVS、終端、GH渡りコネクタ。
4. 各部品について、採用根拠、定格計算、データシートURL/版数、配置配線制約を記録する。

### フェーズC: 共通KiCadブロック

1. `g474_minimum`
2. `power_5v_3v3`
3. `can_interface`
4. `stdc14_debug`
5. `status_led`

各ブロックは単独でERCし、PDF出力して目視レビューする。

### フェーズD: ユニット基板固有ブロック

1. AMT222A SPI。
2. C620 CANとコネクタ。
3. UNIT_ID、ADC監視、テストポイント。
4. ルートシートへ共通ブロックを統合してERCする。

### フェーズE: オドメトリ基板固有ブロック

1. AMT102入力方式の比較・選定・6ch回路。
2. IMU比較・選定・SPI/Data Ready回路。
3. unitId、ADC監視、テストポイント。
4. ルートシートへ共通ブロックを統合してERCする。

### フェーズF: 中央基板固有ブロック

1. Teensyソケットと全ピンマップ。
2. CAN x3。
3. 5V入力・スター分配・枝保護。
4. E-stop監視、コンタクタドライバ、24Vセンス。
5. バッテリー監視、状態LED、拡張I/O、サービス端子。
6. 全体ERC、BOM、電源ピン/コネクタ整合チェック。

### フェーズG: 人によるPCB配置配線

AI側は各回路ブロックについて次の制約表を渡し、人がKiCad GUIで配置・配線する。

| 制約分類 | 例 |
|---|---|
| 最優先近接 | 水晶と負荷容量をMCU OSCピン直近、VDDデカップリングを対象ピン直近 |
| コネクタ近接 | CAN TVSとトランシーバを外部CANコネクタ近く、保護素子をコネクタ側に置く |
| 最大配線長 | 水晶、SPI、CANスタブ、スイッチングノードなどブロックごとに目標を示す |
| リターン経路 | 信号直下の連続GND、デカップリングの最短ループ、GND分断を跨がない |
| 離隔 | IMUを熱源/コネクタ/取付穴から離す、ADCをCAN/コイル/LEDスイッチングから離す |
| 電流/幅 | 電源枝ごとの最大電流から銅厚・温度上昇込みで配線幅を決める |
| サービス性 | STDC14、Program、終端、ID、テストポイントを組付け後も触れる位置に置く |
| シルク/誤挿入 | コネクタの1番、電圧、信号名、終端状態、基板Revを明示する |

配置完了時、配線途中、配線完了時の3回を基本レビュー点とする。AIは画像/PDF/DRC結果とネット別条件を照合し、最終判断と操作は人が行う。

## 完了条件

- P0がすべて解消または明示的にRev.A対象外となっている。
- 全採用部品にメーカー資料と正式発注型番が紐付いている。
- 3基板の電源・CANコネクタのピン順とネット名が一致している。
- 各階層シート単独および基板全体でERCを実行している。
- 配置配線制約表を人が確認してからPCB作業を開始している。

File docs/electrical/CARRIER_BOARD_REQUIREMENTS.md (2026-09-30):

# 差動ステアユニット基板(STM32G474自作基板)要件

> **2026-09-26 C620終端確定:** 駆動V2のGHポート2個から各ESCへ接続し、各ESCの120Ω終端をON。ESC①―基板―ESC②の両端終端とし、基板側C620終端は搭載しない。旧C620終端抵抗/スイッチの部品表記には本指定を優先する。中央CAN側の終端は別系統。

> **2026-09-26 駆動V2確定:** AMT22基板側J6はケーブルに合わせて1=CS、2=MISO、3=GND、4=MOSI、5=SCLK、6=+5V。センサ側との対応は1→6、2→5、3→4、4→3、5→2、6→1で、旧ストレート結線の記述には優先する。5V監視はR13=33kΩ（5V側）/R14=22kΩ（GND側）、分圧比0.4。V2換算はVin=ADC/4095×3.3/0.4。V1実装22k/10kとは区別する。

> **V2改版（2026-09-23着手）**: デバッグ・TP・V1修正の変更要件は[共通V2要件](UNIT_ODOMETRY_V2_REQUIREMENTS.md)を優先する。本文のGH6/SWD・UART一体配列はV1仕様。V2の正式ヘッダ型番とPCB配線は未確定/未完了。

## 目的

各差動ステアユニットに載せる、STM32G474直載せの自作基板をKiCadで設計する。

> **確定(2026-07-02): キャリアボード方式は不採用。STM32G474を直接実装した自作基板とする。**
> 購入済みのMatek CAN-G474を主なファーム開発・2バスCAN検証用に使い、NUCLEO-G474REはSWD・ピン自由度が必要な場合の予備とする。CAN-G474はG474CE(LQFP48)であり、G474RET6向け現行ファームを無変更では使えない。
> 回路・実装の参考としてMatek CAN-L431、Matek CAN-G474、ARK CANnode、CANable 2.0を使う。ただし各基板の電源条件、MCU、CAN系統数、トランシーバ、保護回路の差を確認し、ブロック単位で採否を決める。基板全体の無検証コピーはしない。
> FDCANの具体ピン(FDCAN1: PA11/PA12またはPB8/PB9、FDCAN2: PB12/PB13等)はCubeMXで割当を確定する。NUCLEOでの検証時も同じピン割当を使うこと。

パッケージはNUCLEO-G474REと同じ**LQFP64のSTM32G474RET6で確定**とする(2026-07-17、10個購入済み)。0.5mmピッチで、フラックス+ドラッグはんだまたはリフローで実装可能。Flash 512KBで将来の制御・診断・更新機能にも余裕があり、NUCLEOで検証したピン割当をそのまま使える。

## 参考ボードと利用範囲(2026-07-06確定)

| ボード | 主な参照箇所 | この設計との差 |
|---|---|---|
| [Matek CAN-L431](https://www.mateksys.com/?portfolio=can-l431) | 購入済み実機。5V入力、CANコネクタ、1Mbps CANの配線・終端・実装、ベンチ通信試験 | STM32L431、CAN 1系統。最終2バス構成の代用にはならない |
| [Matek CAN-G474](https://www.mateksys.com/?portfolio=can-g474) | 購入済み主試験機。STM32G474、CAN 2系統、SWD、電源、コネクタ配置、ArduPilot hwdefのピン割当 | STM32G474CE(LQFP48)で、本基板のG474RET6(LQFP64)とはパッケージと露出ピンが異なる |
| [ARK CANnode](https://github.com/ARK-Electronics/ARK_CANNODE) | 公開回路/BOM、MCU最小構成、5V→3.3V、CAN、SWD、保護・デカップリング | STM32F412、CAN 1系統、DroneCANセンサ用途 |
| CANable 2.0 | 公開回路、STM32G4最小構成、CANトランシーバ、USB-CAN実装 | USB-CAN用途。USB回路は本基板では原則不要 |

Matek CAN-G474のファーム用ピン定義はArduPilotの`MatekG474` hwdefを参照する。公開回路図が確認できない箇所は、基板写真やhwdefだけから回路定数を推測せず、STM32/TI等の部品データシートを正本とする。

## MCU最小構成(CANable流用部分+G474固有)

| 項目 | 要件 |
|---|---|
| VDDデカップリング | 各VDDピンに`GRM188R71A104KA01D` 100nF + 全体に`GRM21BR71A475KA73L` 4.7uF。LDO側10uFも併用 |
| VDDA/VREF+ | `BLM18AG601SN1D`後にVDDA 100nF+1uF。VREF+はVDDAへ0Ω接続し10nF+1uF。ADCを使うため省略しない |
| NRST | 100nF + デバッグGH6 + SMTテストポイントへ引き出し。内部weak pull-upを使い外付けpull-upなし |
| BOOT0 | `RC0603FR-0710KL` 10kΩ pull-down + BOOT0/3V3隣接SMTテストポイント。2.54mmジャンパは載せない |
| クロック | **`FC3BAEBDI8.0-T1` 8MHzを実装し、C0G 10pF x2を初期値とする(2026-09-06調達変更)。** CL=8pF、ESR max 500Ω、3225-4padを旧ECS品から維持する。負荷容量は実基板評価で8.2/10/12pFから調整。ファームはHSE起動+CSSでHSIフォールバック |
| SWD/デバッグUART | **ロボット側JST GH 6pinへ統一。** 1=GND、2=SWCLK(PA14)、3=SWDIO(PA13)、4=NRST、5=DBG_TX(PA2、ターゲット→デバッガ)、6=DBG_RX(PA3、デバッガ→ターゲット)。WeActStudio MiniDebugger側SH 10pinとの専用変換ケーブルを使う。SWO(PB3)は基板上テストパッドへ残す。デバッガ側5V/3.3Vは接続せず、ターゲットを通常の5V入力から自己給電する |
| デバッグUART | 1ch分をヘッダに出しておく(printf/ログ用) |

初回書き込み・ブリングアップ手順は `firmware/docs/BOARD_BRINGUP.md` の「自作基板へ移行するときのSWD要件」に従う。

## 推奨ピン割当(STM32G474RET6 / LQFP64)

NUCLEO-G474REのmorphoに全ピンが出ており、開発ボードと自作基板で同一割当を使える構成。

> **AF成立確認済み(2026-07-06)**: ST公式の[STM32_open_pin_data](https://github.com/STMicroelectronics/STM32_open_pin_data)(CubeMXと同一DB、`STM32G474R(B-C-E)Tx.xml`)で下表全ピンの信号割当を照合し、全て成立を確認した。FDCAN1_RX/TX=PA11/PA12、FDCAN2_RX/TX=PB12/PB13、SPI3=PC10/PC11/PC12、LPUART1_TX/RX=PA2/PA3、I2C1_SCL/SDA=PA15/PB7、SWO=PB3、BOOT0共用=PB8、OSC=PF0/PF1。なおG4のNRSTピンはPG10(LQFP64のpin7)。CubeMXでの.iocプロジェクト化は未実施(ファーム設定時に行う)。

| 機能 | ピン | AF | 備考 |
|---|---|---|---|
| FDCAN1_RX(中央CAN) | PA11 | AF9 | USB共用ピンだが本基板はUSB不使用 |
| FDCAN1_TX(中央CAN) | PA12 | AF9 | |
| FDCAN2_RX(C620) | PB12 | AF9 | |
| FDCAN2_TX(C620) | PB13 | AF9 | PB13をSPI2に使わないこと |
| SPI3_SCK(AMT22) | PC10 | AF6 | |
| SPI3_MISO(AMT22) | PC11 | AF6 | |
| SPI3_MOSI(AMT22) | PC12 | AF6 | |
| AMT22_CS_N | PD2 | GPIO | バイト間ウェイトが必要なのでソフト制御CS |
| デバッグUART | PA2 / PA3 | LPUART1 | NUCLEOのST-LINK VCPと同一。開発時printfがそのまま使える |
| UNIT_ID0/1/2 | PC6 / PC7 / PC8 | GPIO入力 | 内部プルアップ、3bit DIPスイッチでGNDへ(ON=Low、読み値反転)。起動時に1回読取り、RUN LEDをID回数点滅 |
| LED(電源/動作) | PA5 | GPIO | NUCLEOのLD2と同一。開発時の動作確認互換 |
| LED(通信) | PB10 | GPIO | |
| LED(エラー) | PB11 | GPIO | |
| 5V監視 | PA0 | ADC | 22kΩ(R13)/10kΩ(R14)分圧+10nF+Comchip `BAT54S-HF`クランプで保護後5Vを監視 |
| SWD | PA13 / PA14 | - | 専用。他用途に使わない |
| SWO(予約) | PB3 | - | トレース用に空けておく |
| BOOT0 | PB8 | - | G4はPB8がBOOT0共用。10kプルダウン+ジャンパ。GPIOとして使わない |
| HSE水晶 | PF0 / PF1 | - | 8MHz |
| 拡張I2C(予約) | PA15(SCL) / PB7(SDA) | AF4 | IMU等の将来拡張用。ヘッダに出しておく |

選定理由:

- FDCAN1にPB8/PB9を使わない: PB8はBOOT0共用のため。
- AMT22をSPI1(PA5/PA6/PA7)にしない: PA5がNUCLEOのLD2と衝突し、開発時に不便なため。SPI3(PCポート)は競合がない。
- PC13を使わない: NUCLEOのB1ボタンと衝突するため。
- NUCLEO検証時はPA2/PA3がST-LINK VCP直結なので、デバッグUARTがUSB経由でそのまま見える。

## 外部インターフェース

| 信号 | 用途 |
|---|---|
| 5V | 制御電源 |
| GND_CTRL | 制御GND |
| COMM_A / COMM_B | 中央制御との通信。実体は中央CANのCAN_H/L |
| C620 CAN | C620 x2との通信 |
| AMT22 SPI | ステア角取得 |
| ID DIPスイッチ | ユニットID設定(3bit) |

C620用24V大電流線はキャリア基板の制御ハーネス(5V/GNDのGH 2pin、COMM_A/B/GNDのGH 3pin)と分ける。

## 中央通信(中央CAN)

要件:

- 各ユニットに中央CAN用トランシーバを1個載せる(C620用とは別に、計2個)。
- 中央駆動CANはCAN FD、nominal 1Mbps/data 2Mbps、BRS有効。ノードはTeensy CAN3+G474ユニットx3。
- 外部コネクタのシルクは `COMM_A/B` とする(`CAN_H/L` とは書かない)。
- MCU側ネットは `COMM_TX` / `COMM_RX` とし、FDCAN1に割り当てる(C620はFDCAN2)。

バス全体の要件:

- トポロジはデイジーチェーン(渡り配線)とし、スター配線にしない。
- 120Ω終端はバス物理両端の2箇所のみ。Teensy側1個+最遠ユニット1個。各キャリアには`RC0603FR-07120RL`と`JS102011SAQN`スライドスイッチを載せ、末端ユニットだけONにする。
- COMM_A/Bラインに`ESD2CAN24DBZRQ1`を入れる。
- CANはドミナント/リセッシブ方式なので、RS485で必要だったDE/RE制御やフェイルセーフバイアスは不要。

部品選定: C620側と共通化して **`TCAN1051VDRQ1` x2** とする。VCC=5V、VIO=3.3V。
中央側は同部品のCAN FD 2Mbps対応を使い、C620側はClassic 1Mbpsで使う。詳細は
`CAN_COMMON_BLOCK_PART_SELECTION.md`。

## C620 CAN

要件:

- 各ユニットにC620専用CANトランシーバを1個載せる。
- MCUのCAN_TX/CAN_RXをCAN_H/CAN_Lへ直結しない。
- C620_CAN_H/Lはユニット内だけで使う。
- ユニット内CANの終端120Ωは実配線長とC620側終端有無を確認して決める。
- スタブを短くする。
- トランシーバ近傍に0.1uFを置く。
- C620のCANビットレートは1Mbps固定。FDCANはクラシックCAN 1Mbpsで設定する。
- C620のIDはSETボタンで設定する(ユーザーガイド参照)。ユニット内で#1/#2を組立時に設定し、ケースに明記する。
- CAN_H/Lに`ESD2CAN24DBZRQ1`を入れる。

部品選定:

| 候補 | 備考 |
|---|---|
| `TCAN1051VDRQ1` (TI) | **採用**。5V VCC、3.3V VIO、SOIC-8、バスフォルト±58V、AEC-Q100 |
| `TJA1051T/3` (NXP) | 基本ピン配列が一致する代替候補。公開CAN設計での採用実績が多い |

## AMT22 / SPI

型式確定(2026-07-02): **AMT222A-V**(12bitシングルターン、radial、ボア5mm)。分解能4096cnt(0.088°/cnt)。ステア軸に1:1直結。12bit応答の下位2bit(L0/L1)は常に0なので、読み値は2bit右シフトして使う。

AMT22は5V駆動(VDD 3.8〜5.5V)、MCUは3.3V系。

データシート確認済みの電気仕様(Same Sky AMT22 rev1.09):

| 項目 | 値 |
|---|---|
| 入力High(VIH) | min 2.0V / max 5.5V |
| 出力High | 3.3V |
| SPIモード | Mode 0 |
| 最大クロック | 2MHz |

結論: **全信号直結でよい。MISO分圧は不要。**

| 信号 | 方向 | 対策 |
|---|---|---|
| SCLK | MCU -> AMT22 | 直結(VIH 2.0Vなので3.3V駆動で成立) |
| MOSI | MCU -> AMT22 | 直結 |
| CS | MCU -> AMT22 | 直結 |
| MISO | AMT22 -> MCU | 直結(AMT22出力Highは3.3V)。保険で100Ω直列を入れてもよい |

タイミング制約(ファーム実装で必須):

| 項目 | 値 |
|---|---|
| T_CLK: CS↓から最初のクロックまで | ≥2.5µs |
| T_B: バイト間 | ≥2.5µs |
| T_R: 最終クロックからCS↑まで | ≥3µs |
| T_CS: リード間隔 | ≥40µs |

バイト間ウェイトが必要なため、2バイトを連続DMA転送すると読めない。1バイトずつ送る。応答上位2bitはチェックビット(奇偶パリティ)なので必ず検証する。

コネクタ: AMT22側はMolex 502578-0600(Pico-Lock 6pin)。検証用ケーブルはAMT-06C-1-036。キャリア側はJST GH 6pin横挿し(`SM06B-GHS-TB`)で中継し、Pico-Lock⇔GHの変換ハーネスを作る(GH側ハウジングはデバッグ用と共通の`GHR-06V-S`+`SSHL-002T-P0.2`)。

AMT22コネクタのピン配置(データシートrev1.10で確認済み、`hardware/reference/datasheets/`に保存):

| ピン | 機能 |
|---:|---|
| 1 | +5V |
| 2 | SCLK |
| 3 | MOSI |
| 4 | GND |
| 5 | MISO |
| 6 | CHIP SELECT |

基板側GH 6pinも同じピン順にすると、ハーネスがストレート結線になる。

## 電源

| 入力 | 用途 |
|---|---|
| 5V | NUCLEO、AMT22、LDO入力 |
| 3.3V | STM32G474、CANトランシーバVIO、ロジック等 |

ユニットへの給電は中央から独立したGH 2pinの5V/GNDで受ける。CANのGH 3pinとは別ハーネスとする。基板入力を`LM66100DCKR`で逆接・逆流保護し、保護後5VからLDOで3.3Vを作る。

`TCAN1051VDRQ1`の主電源VCCは5V、3.3V側はVIOだけである。3.3V負荷を150～300mAと仮定するとLDO損失は0.255～0.510W。SOT-223のVOUTタブへ放熱銅箔を設け、最大負荷で温度を実測する。1A定格をそのまま連続使用可能電流とは扱わない。

| 候補 | 備考 |
|---|---|
| `TLV1117LV33DCYR` | 生産中止のため2026-09-06に調達対象から除外 |
| `TLV76133DCYR` | **採用**。1A、SOT-223、1=GND/2=VOUT/3=VIN/タブ=VOUT、1µF以上のセラミック出力コンデンサで安定 |
| `MCP1826S-3302E/DB` | 成立するが、少量価格と流通性から代替候補 |

保険として、5V入力部に**広入力レンジ降圧モジュールのフットプリントを予備実装として置く**ことを推奨する(例: OKI-78SR-5/1.5-W36-C、三端子レギュレータ互換ピン配置、入力7〜36V)。ハーネスの電圧降下で5V分配が苦しくなった場合、配線を24V分配に切り替えて同じ基板で受けられる。通常時は未実装+ジャンパでバイパス。

注意:

- LDO近傍に入力側100nF+10uF X7Rを置く。
- LDO出力側に100nF+10uF X7Rを置き、DC bias後もデータシート最小容量を満たす。
- 5VがAMT22の上限5.5Vを超えないようにする。
- AMT22は起動に最大200ms要し、起動中はシャフト静止が必要。ファームの初期化待ちに反映する。

## 部品リスト

| ブロック | 部品 | 実装 |
|---|---|---|
| 中央CAN | `TCAN1051VDRQ1` | SOIC-8、リフロー |
| 中央CAN終端 | `RC0603FR-07120RL` + `JS102011SAQN` | 120Ω + SMTスライドスイッチ |
| 中央CAN保護 | `ESD2CAN24DBZRQ1` | SOT-23、リフロー |
| C620 CAN | `TCAN1051VDRQ1` | SOIC-8、リフロー |
| C620 CAN終端 | 基板側は非搭載 | 2026-09-26確定: 各GHから接続するESC2台の両端120ΩをON |
| C620 CAN保護 | `ESD2CAN24DBZRQ1` | SOT-23、リフロー |
| 5V入力保護 | `LM66100DCKR` | SC70-6、CE_N=VOUT、1.5A、RPP+RCB |
| LDO | `TLV76133DCYR` | SOT-223、タブ=VOUT。旧TLV1117LV33DCYRと同一ピン配置 |
| MCU | STM32G474RET6(LQFP64) | 0.5mmピッチ、ドラッグはんだ |
| 水晶 | `FC3BAEBDI8.0-T1` + `CL10C100JB8NNNC` x2 | 8MHz、CL=8pF、ESR max 500Ω、3225-4pad、10pF C0G x2 |
| SWD/デバッグUART | JST GH: `GHR-06V-S` + `SSHL-002T-P0.2`、基板側は上挿し`BM06B-GHS-TBT` | WeAct SH 10pin→ロボットGH 6pin専用ケーブルを作る |
| BOOT0 | `RC0603FR-0710KL` + BOOT0/3V3 `S1751-46R` | 10kΩ pull-down、隣接TPを治具で短絡 |
| ID設定 | 3bit DIPスイッチ(型番は部品選定で確定) | PC6-8、内部プルアップ、ON=GND短絡。起動時にRUN LEDをID回数点滅、ID=0(全OFF)は未設定エラー扱い |
| デカップリング | VDD 100nF x4 + 4.7uF、VBAT 100nF、VDDA用`BLM18AG601SN1D`+100nF+1uF、VREF+ 10nF+1uF | 0603/0805、詳細はG474最小構成選定書 |
| AMT22中継 | `SM06B-GHS-TB` + `GHR-06V-S` + `SSHL-002T-P0.2`(AMT22側は純正Molex Pico-Lockケーブル、変換ハーネス自作) | 横挿しGH6、1.25mm、AMT22と同ピン順でストレート結線 |
| 外部電源 | `SM02B-GHS-TB` + `GHR-02V-S` | 横挿しGH2、1=5V、2=GND、AWG26、CANと分離 |
| 中央CANパススルー | 横挿しJST GH 3pin x2(COMM_A/COMM_B/GND) | `SM03B-GHS-TB`、基板上でIN/OUT直結 |
| 予備降圧 | OKI-78SR-5互換フットプリント + バイパスジャンパ(通常未実装) | スルーホール |
| 5V監視 | R13 22kΩ(5V側)/R14 10kΩ(GND側) + 10nF + Comchip `BAT54S-HF` | PA0、0.3125倍、dual-series SOT-23クランプ。2026-09-21に33kΩ/22kΩ(0.4倍)から変更(33kΩ現物なし)。ADCスケールは`Vin = ADC/4095*3.3/0.3125` |
| 状態LED | `LTST-C190KGKT`緑、`LTST-C190KSKT`黄、`LTST-C190KRKT`赤 + 各1kΩ | PWR/RUN/COMM/ERRの4表示、0603 |
| テストポイント | `S1751-46R` | 主要5V/3.3V/GND/CAN/NRST/BOOT0/SWO。補助信号は露出銅pad |

## 回路図作成メモ(2026-07-06確認)

KiCad 10標準ライブラリに以下の検証済みシンボルがあり、ピン配置の正本として使える(自作シンボル起こし不要):

| 部品 | シンボル | 確認済みピン |
|---|---|---|
| STM32G474RET6 | `MCU_ST_STM32G4:STM32G474RETx` | 64pin。NRST=PG10(pin7)、BOOT0=PB8(pin61)、VDD=16/32/48/64、VSS=15/31/47/63、VDDA=29、VSSA=27、VREF+=28、VBAT=1 |
| `TCAN1051VDRQ1` | 自作または検証済み互換シンボル | 1=TXD、2=GND、3=VCC(5V)、4=RXD、5=VIO(3.3V)、6=CANL、7=CANH、8=S |
| `TLV76133DCYR` | `Regulator_Linear:TLV1117-33`を公式pinoutと照合 | 1=GND、2=VOUT、3=VIN、タブ=VOUT。既存footprintを変更せず実装可 |
| `LM66100DCKR` | `Power_Management:LM66100DCK` | 1=VIN、2=GND、3=CE_N、4=NC、5=ST、6=VOUT。CE_N→VOUTでRPP+RCB |
| OKI-78SR-5(予備降圧) | `Converter_DCDC:OKI-78SR-5_1.5-W36-C` | 7805互換3pin |

`ESD2CAN24DBZRQ1`は公式データシートでピン配置とSOT-23(DBZ)推奨ランドを確認し、KiCad標準シンボル/フットプリントの一致を検証する。不一致なら`hardware/lib/`に自作シンボルを起こす。

ARK CANnode Rev 1回路図(`hardware/reference/ARK_CANNODE/`)から流用検討する回路ブロック:

- 逆接・逆流保護: `LM66100DCKR`(VIN側2.2uF以上、CE_N=VOUT、1.5A、RPP+RCB)
- CANコネクタを同一バスで2個並列に載せ、基板上でデイジーチェーンの渡りを作る(中央CANの渡り配線と一致する構成)
- 外部に出る信号線に1ラインESDダイオードを挿入
- 終端120ΩをFETで切替(本基板は物理スライドスイッチ方式なので参考のみ)

## 評価ボードとの関係

(旧「第二段階への移行」。2026-07-02に自作基板方式へ一本化したため、MCU最小構成は冒頭の必須要件に統合した)

- Matek CAN-G474を2系統CANとG474上での主なファーム検証に使う。公式/ArduPilot hwdef上のCAN割当はCAN1=PA11/PA12、CAN2=PB5/PB6。
- CAN-G474でAMT22を接続する場合は、基板上に露出しているSPI2(PB13/PB14/PB15、CS=PB12)へボード別設定を追加する。現行NUCLEO用SPI3(PC10/PC11/PC12、CS=PD2)のままでは使えない。
- NUCLEO-G474REはSWDの確実な復旧、自由なピン引き出し、現行ファームの回帰確認用として保持する。CAN-G474のカスタムファーム書込みと必要I/Oが確認できれば、通常試験では省略可能。
- ピン名はNUCLEOコネクタ番号ではなく `PAx` / `PBx` で管理し、自作基板とNUCLEOで同じ割当を使う。これによりファームを無改造で移植できる。
- NUCLEOで使用済みのピン(LD2=PA5、B1=PC13、VCP=PA2/PA3)は、自作基板では自由に使えるが、NUCLEO検証中は避けるか競合を理解して使う。
- 将来さらに小型化する場合もFDCAN 2系統以上のMCU(STM32G474/G473系)を維持する。STM32G431K系はFDCAN 1系統なので不可。

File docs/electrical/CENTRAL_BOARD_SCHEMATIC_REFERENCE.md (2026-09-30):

# Teensy 4.1中央基板 Rev.A 回路図リファレンス

> 2026-09-23: 本文は旧Rev.Aの参考。次回製造のCAN端子とコイルdriver搭載境界は最新一括発注計画に従う。中央回路図は改訂PDFを人が転記する。 詳細: [次回PCB一括発注計画](PCB_BATCH_V2_CENTRAL_PLAN.md)。

作成: 2026-08-04
状態: 人間レビュー用KiCad回路図の接続正本。`hardware/central-board/central-board.sch`をrootとする責務別6 child sheetsと同時に照合する。

> **Rev.1注記(2026-09-14)**: Rev.1(コンタクタドライバ・24Vセンス・INA238を持たない構成)のKiCad転記用接続表は`CENTRAL_BOARD_REV1_KICAD_ENTRY_REFERENCE.md`を使う。本書のD2(コンタクタドライバ)、D4(モータバス電圧)、E(INA238部分)はRev.1で不採用。

## Rev.Aの範囲

搭載するもの:

- Teensy 4.1ソケット、micro USBサービス空間
- CAN1/CAN2/CAN3トランシーバ、ESD、切替式120ohm終端、各バスIN/OUTコネクタ
- 5V主入力保護、4ノード＋Teensy＋拡張のスター分配
- E-stop直列ループ、個別補助接点監視、コンタクタコイルドライバ
- コンタクタ後24Vセンス、購入済みMatek I2C-INA-BMによる外部電流・電圧監視
- 物理再アームボタン、基板状態LED、I2C/UART/SPI/GPIO拡張

載せないもの:

- C620主電流、外付け100Aシャント、メインコンタクタ本体
- 24V表示灯・電磁弁・LEDテープの電力ドライバ
- 24V→5V DC-DC、24V→12V DC-DC
- Ethernet magjack、USB Host、追加3.3V LDO

## A. 5V主入力・スター分配

### A1. 主入力

```text
J1 XT30PW-M
  1 = +5V_IN
  2 = GND_CTRL

+5V_IN -> TPS259470LRPWR -> +5V_SYS
```

- J1正式型番はAMASS `XT30PW-M`、横向きTHT、連続15A定格。5A入力に使用する。
- U1はTI `TPS259470LRPWR`。真の逆流阻止、突入、過電流、過熱を扱い、USB接続中に`+5V_SYS`からDC-DC側へ逆流させない。入力逆極性保護はTPS259470の内蔵back-to-back FETで扱う（連続5Aに使えない`LM66100`や別series diodeは中央主入力へ追加しない）。ただし絶対最大はIN=28V、負電圧=-15Vなので、24V側の大きなサージを5V出力へ通さないことはDC-DC側の責務とする。
- `RILM=750ohm`を初期値とし、過電流閾値はtyp 4.45A。想定1〜2A負荷に十分な余裕を持たせつつ、5A DC-DCと配線を保護する。
- SD-25B-5を5.00Vへ調整・封印した前提で、UVLO/OVLO dividerは1% `R102=732k` (IN→EN/UVLO)、`R103=51.1k` (EN/UVLO→OVLO)、`R104=221k` (OVLO→GND) とする。typ設定値はUVLO rising約4.43V、OVLO rising約5.46V。これは異常時の切離しであり、SD-25B-5の出力trimを5.5Vまで上げてよい意味ではない。組立時に無負荷/定格負荷で5.00V±0.10Vを記録する。
- `dVdt`は全枝の実装容量を積算し、起動時の出力立上り20〜50msを目標に決める。初版は`C_dVdt=10nF`（5Vでtyp約25ms）とし、22nF/47nFへ交換可能にする。
- U1直近に1uF入力、1uF出力、J1近傍に100uF/10V、スター点に470uF/10V low-ESRを置く。`FLT`は10kohmで3.3Vへpull-upし`PWR_5V_FAULT_N`へ接続する。
- `FLT`は10kohmで3.3Vへpull-upし`PWR_5V_FAULT_N`へ接続する。
- 2mm角QFNのため、データシート推奨land patternと熱viaを使用し、表裏GND copperへ放熱する。

### A2. 枝

| 枝 | 保護 | コネクタ/接続 | LED |
|---|---|---|---|
| Unit 1 | `1206L050/15YR` | `SM02B-GHS-TB`, 1=5V, 2=GND | 緑+1.5kohm |
| Unit 2 | `1206L050/15YR` | 同上 | 同上 |
| Unit 3 | `1206L050/15YR` | 同上 | 同上 |
| Odometry | `1206L050/15YR` | 同上 | 同上 |
| Teensy | `1206L075/16WR` | VINへ基板内接続 | 緑+1.5kohm |
| Expansion 5V | `1206L050/15YR` | GH拡張電源 | 緑+1.5kohm |

PPTC後を個別ネット`+5V_UNIT1`等とし、各枝へtest pointを置く。PPTCの高温deratingと突入は実機で確認する。

## B. Teensyソケット

- 回路図では1x24 connectorを2個使い、socket pad番号1〜48を`TEENSY41_CENTRAL_PIN_ASSIGNMENT.md`どおりに割り当てる。
- ソケットはPJRC推奨のSullins `PPPC241LFBN-RC`または`PPTC241LFBN-RC` x2を第一候補とする。Teensy側header候補はAmphenol `68000-224HLF`。
- 列中心間15.24mm。Teensy外形60.96mm x 17.78mmとmicro USB plugの抜差し領域をF.CrtYd相当のkeepoutにする。
- Teensy直下は裏面実装部品との干渉を避けるため、部品、test point、露出pad/copperを全面禁止する。microSD、Program button、micro USBの交換・操作空間も塞がない。
- 組立工程にVUSB-VINパッド切断と導通検査を入れる。

### B1. USB給電diode-OR(2026-09-12追加)

```text
+5V_SYS -> D1(Schottky) -\
                           +-> VIN(pad48)
Teensy VUSBパッド -> D2(Schottky) -/
```

- VUSB-VINパッドは従来通りカット。カット後のVUSBパッドからD2を介してVINへ接続する。
- D1/D2はNexperia `PMEG2010EA,115`（20V/1A low-VF、SOD-323）を初期指定とする。逆流はTPS259470側で別途保護済みのためD1はOR用途のみ。
- ~~外部5V枝をUSBから給電させない~~ → 2026-09-26撤回。USBからも第2 eFuse経由で`+5V_SYS`へ給電する(B2)。

### B2. USB→+5V_SYS 給電(2026-09-26追加)

```text
Teensy VUSB -> U102 TPS259470ARPWR (ILIM≈1A, auto-retry) -> +5V_SYS
+5V_RAW -> 100k/37.4k -> U102 OVLO   (外部5V≥4.41VでU102 OFF = 外部5V優先)
```

- USBだけでCAN x3とノード1基分(ユニット or オドメトリ)の5Vを動かすため。定数・接続表は`CENTRAL_BOARD_REV1_KICAD_ENTRY_REFERENCE.md` 3.1節が正本。
- D2(VUSB→VIN)は残す。外部5Vの抜き差し時とU102の電流制限時にTeensyのUSB接続を切らさないため。

## C. CAN x3

各バスは`CAN_COMMON_BLOCK_PART_SELECTION.md`の同一回路を使う。

| bus | Teensy | 初期実装 | 通信 |
|---|---|---|---|
| CAN1 Sensor | pin 22/23 | 実装 | Classic CAN 1Mbps |
| CAN2 Expansion | pin 0/1 | 実装 | Classic CAN 1Mbps初期値 |
| CAN3 Drive | pin 31/30 | 実装 | CAN FD nominal 1Mbps/data 2Mbps+BRS |

- U2/U3/U4: `TCAN1051VDRQ1`、VCC=5V、VIO=3.3V、各電源pinへ100nF。
- connector -> `ESD2CAN24DBZRQ1` -> bus trunk -> transceiverの順に置く。
- 各バスに横挿しGH3を2個並列配置し、1=`COMM_A`、2=`COMM_B`、3=`GND_CTRL`。バス名は`SENSOR_COMM_*`、`EXP_COMM_*`、`DRIVE_COMM_*`のprefixで回路図内を区別する。
- `RC0603FR-07120RL`と`JS102011SAQN`を直列にした終端を各バスへ1組置く。スイッチ近傍へ`TERM ON/OFF`を表示する。
- CAN3差動pairは100ohm differentialを目標、同一層・連続GND reference・スタブ10mm以下とする。CAN1/2も同じ配置規律を使う。

## D. 24V安全回路

### D1. コネクタとハードループ

```text
+24V_CTRL_IN
  -> F1 250mA fuse
  -> ESTOP_LOOP_OUT
  -> E-stop 1 NC
  -> E-stop 2 NC
  -> ESTOP_LOOP_RETURN
  -> contactor coil +
  -> contactor coil -
  -> Q1 drain/source
  -> GND_CTRL
```

- `24V_CTRL_IN`と`CONTACTOR_COIL`は誤挿入を避けるため別キー/明確な色表示を持つロック付き2pin connectorとする。
- `ESTOP_CTRL`はMolex Micro-Fit 3.0 single-row header `43650-0600`、相手housing `43645-0600`。dual-row housing `43025-0600`とは嵌合しない。既定の6pin割当は`CENTRAL_BOARD_REQUIREMENTS.md`に従う。
- 安全ループ用F1とLED/補助接点用F2を分離する。F2短絡でF1が開かないことを配線試験する。

### D2. コンタクタドライバ

- Q1: `IRLML0100TRPBF`, 100V N-channel SOT-23。80mAコイルではVGS=3.3V時にRds(on)が悪化しても発熱余裕が十分あることを試作で確認する。
- Gate: Teensy -> 100ohm -> Gate、Gate-Source 47kohm pulldown。Teensy未起動時はOFF。
- coil clampはdiode+TVSを第一候補とし、TVS電圧はE228の解放時間とQ1 VDS実測から確定する。`1N4007`単独の低電圧clampは解放を遅くするため初期案にしない。
- coil connector近傍にD1、Q1、24V/GND test pointをまとめる。コイル電流は大電流GND面を横断させず24V I/O領域で閉じる。

### D3. E-stop監視

- U5: `LTV-847S` 4ch optocoupler。ch1=直列ループ、ch2/3=個別補助接点、ch4=予備24V入力。実pinはch1=`A1/K2, C16/E15`、ch2=`A3/K4, C14/E13`、ch3=`A5/K6, C12/E11`、ch4=`A7/K8, C10/E9`で固定する(**2026-09-14訂正**: 旧記載「ch1=E9/C10 … ch4=E15/C16」はLite-On BNS-OD-C131/A4の内部接続図と不一致。DIPのミラー対でLED 1/2はTr 16/15と組む。`reference-2026-09-12/`の安全シートは旧対応のままなので流用しない)。
- `LTV-847S`は標準SOIC-16ではない。購入リール実物とLite-On outlineを照合して、wide 2.54mm-pitch SMD用の専用footprintを`hardware/lib/`へ起こすまでPCBフットプリントは空欄とする。
- 各使用入力は2.2kohm x2直列（R10A/R10B等）と`1N4148W`のLED逆並列保護を置く。24V時は約5mA、抵抗合計4.4kohmの損失は約0.12Wなので各0603へ約60mWずつ配分される。24V制御電源の上限を30Vとしても各抵抗は約75mWに留める。
- transistor側は各chのcollectorを10kohmで3.3Vへpull-up、emitterをGND_CTRLへ接続する。Low=接点成立なので`*_OK_N`と命名する。
- フォトカプラは診断用であり、安全遮断の主経路ではない。

### D4. モータバス電圧

- コンタクタ後`MOTOR_24V`を100kohm+100kohm / 20kohm (各0.1%)で1/11へ分圧する。
- ADC直前に1kohm、10nF、3.3V対応low-leakage clampを置く。25.2V時は約2.29V。
- 40V印加を1分行ってTeensy ADC pinが絶対最大を越えないことを試験する。ファーム換算係数は実測校正値を保存する。

## E. バッテリー電圧・電流監視

- 購入済みのMatek `I2C-INA-BM`を中央PCB外へ置く。内蔵INA228/INA238系と200uΩ typシャントで、主電源の正側をモジュールのBAT+側からESC+/負荷側へ直列に通す。中央PCBに主電流もKelvin sense harnessも入れない。
- 中央PCBのJ20はJST-GH 4pinで、**pin 1=GND、pin 2=I2C0_SDA、pin 3=I2C0_SCL、pin 4=+5V_SYS**。Matekは5V pinへ4〜9Vを要するため、Teensyの3.3V枝には接続しない。
- I2C addressは既定のdecimal 69（0x45）。必要時だけモジュールのaddress jumperで68（0x44）または65（0x41）へ変更する。`BAT_MON_ALERT_N`はこのモジュール接続では使用しない。
- 公称は0〜85V、連続150A／burst 204.8A、電流精度±2%。内蔵シャント損失は200uΩ typなので、83Aで約1.38W、150Aで約4.5W。電源線・端子・熱設計が連続電流を満たすことを実機確認する。
- I2C信号のプルアップ電圧はモジュール実装状態で確認する。Teensy GPIOへ5Vを印加しないこと（3.3V logicであること）を通電前の必須確認とする。

## F. 操作・拡張

- `REARM_SW_N`: 基板上タクトスイッチ、10kohm pull-up、100nF。GUIだけではコンタクタを再励磁できない。
- status LED: 赤/緑を各1個、GPIOから1kohmを介して駆動。電源LEDと状態LEDをシルクで区別する。
- I2C0/I2C1拡張: GH4、1=3.3V、2=GND、3=SDA、4=SCL。2.2kohm pull-upはsolder jumperで切離し可能。Matek用J20は別系統で、1=GND、2=SDA、3=SCL、4=5Vとする。
- UART x2: GH3、1=GND、2=TX、3=RX。
- SPI: GH7、1=3.3V、2=GND、3=SCK、4=MOSI、5=MISO、6=CS0_N、7=CS1_N。
- GPIO/ADC: GH10、1=3.3V、2=GND、3〜10=IO x8。各IOに100ohm直列抵抗。
- 3.3V外部負荷は全拡張合計100mAをRev.A上限とし、Teensy推奨外部250mAに余裕を残す。

### F1. 拡張ヘッダTVS/アクティビティLED(2026-09-12追加)

```text
GHコネクタ -> SRV05-4(pin5=+3V3_TEENSY, pin2=GND_CTRL) -> Teensy pin
既存信号net(TXD/RXD/SCK等) -> digital transistor -> LED
```

- `SRV05-4`(SOT-23-6、4ch)をI2C(1個・4本)、UART(1個・4本)、SPI(2個・5本使用)、GPIO/ADC(2個・8本)へ計6個配置する。新規Teensy pinは消費しない。
- アクティビティLEDは既存信号netを直接タップし、GPIOを追加消費しない。ただしUART/CANのidle HIGHを単純なNPNへ入れると常時点灯になるため、Rev.AはLED用footprintとtap padのみDNPで残し、RC one-shotまたは専用bufferを別途実測してから実装する。予備pin 33/37/38/39はそのまま温存する。

## G. PCB制約

- 4層、1.6mm、外層1ozを初期条件。L2を連続GND、L3を5V/3.3Vと低速信号に使う。
- 暫定外形100mm x 80mm、四隅M3穴、穴中心を各辺から4mm。機体CAD確定時に外形だけ更新する。
- 左辺: 5V入力と電源枝。上辺: CAN。右辺: 24V安全I/O。下辺: 拡張I/O。中央: Teensy。
- 24V領域、CAN connector領域、アナログsense領域を分離する。L2 GNDは分割しない。
- 5V主幹は4A連続を暫定設計電流とし、表裏copper pour＋via stitchingで配る。eFuse熱padはTI推奨例を優先する。
- USB端から基板外へ15mm以上のplug/cable keepoutを確保する。
- 基板名、Rev、5V/24V、全connector pin、CAN bus名、TERM状態、E-stop pinを機能シルクで表示する。RefDesは製造図で確認できれば基板上非表示でもよい。

## H. ERC/DRC以外の必須試験

1. Teensyを外した状態で5V逆接、出力側5V印加、枝短絡を試験する。
2. USB接続＋外部5V給電でPC側へ逆流しないことを測る。
3. ダミー24V/80mAコイルでE-stop抜去、各NC開放、Teensy reset、MOSFET OFFを試験する。
4. コンタクタ実物でGate、Drain、coil voltageを測り、Q1 VDSと解放時間を確認する。
5. CAN各busを終端60ohm合成、1Mbps、CAN3 FD 2Mbps+BRSで連続試験する。
6. I2C-INA-BMを既知電流でクランプメータと比較し、I2C pull-up電圧・電流値・温度上昇を記録する。

## 参照データシート

- PJRC Teensy 4.1 product page / pinout card
- TI `TPS25947` Rev.C (2026-05)
- Matek `I2C-INA-BM` product page / wiring guide（購入済み外部モジュール）
- Infineon `IRLML0100`
- Lite-On `LTV-8X7` series Rev.S
- PJRC 24x1 header/socket guidance、Sullins `PPPC241LFBN-RC` / `PPTC241LFBN-RC`
- Molex Micro-Fit 3.0 `43650` / `43645`
- AMASS `XT30PW-M` V1.2

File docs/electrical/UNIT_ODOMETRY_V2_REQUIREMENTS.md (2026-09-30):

# 駆動・オドメトリ基板 V2 改版要件

> **2026-09-26 C620終端確定:** 駆動V2のGHポート2個から各ESCへ接続し、各ESCの120Ω終端をON。ESC①―基板―ESC②の両端終端とし、基板側C620終端は搭載しない。旧C620終端抵抗/スイッチの部品表記には本指定を優先する。中央CAN側の終端は別系統。

> **2026-09-26 駆動V2確定:** AMT22基板側J6はケーブルに合わせて1=CS、2=MISO、3=GND、4=MOSI、5=SCLK、6=+5V。センサ側との対応は1→6、2→5、3→4、4→3、5→2、6→1で、旧ストレート結線の記述には優先する。5V監視はR13=33kΩ（5V側）/R14=22kΩ（GND側）、分圧比0.4。V2換算はVin=ADC/4095×3.3/0.4。V1実装22k/10kとは区別する。

> **2026-09-25 ODOM V2確定:** 基板側エンコーダ端子J4/J5/J6は **1=A、2=+5V、3=B、4=GND**。ユーザーがハーネスのねじれ回避のため変更した配列で、V2では本文の旧配列表に優先する。センサ側コネクタの番号とは区別する。

作成: 2026-09-23。対象: STM32G474RET6駆動基板、STM32F405RGT6オドメトリ基板。

**状態: 設計着手。製造用データではない。** V1の機能を土台とし、接続不良の是正、書き込み・測定・段階検証の容易さを優先する。以下の共通デバッグ要件は旧GH6デバッグ仕様に優先する。既存の制御方式・MCU・CANバス構成は変更しない。

## V1実機検証とV2改良を並行（2026-09-23確定）

V1を機能検証機として使い、実測で判明した問題をV2へ反映する。試験ごとに対象個体/ファーム/ジャンパ配線/結果を残し、接続修正台帳へ紐付ける。設計不良と実装不良を区別し、V2設計検査だけで実機確認済みとしない。

V1検証に使うMCU/TCAN/電源ICの回収は、該当検証完了または検証機の移行後に行う。機能確認の順序は電源・SWD→センサ単体→CAN→統合。現在はユーザーがCAN確認を進めている（2026-09-23訂正）。対象バスと試験結果は実機報告に合わせて記録する。

## 1. 作業データと現在地

| 対象 | V2作業プロジェクト | 現在の変更 |
|---|---|---|
| 駆動 | `hardware/unit-board-v2/unit-board.kicad_pro` | J7をCortex Debug 10pinへ変更、VTref/SWO接続、UART J9（2.54mm 1×3、1=GND/2=TX/3=RX）へ置換済み。ERC 0。PCB未反映 |
| オドメトリ | `hardware/odometry-board-v2/Oddom board.kicad_pro` | U3/U7/U9の電源unit C追加、J8をCortex Debug 10pinへ変更、UART J9（2.54mm 1×3、1=GND/2=TX/3=RX）へ置換済み。ERC 0。PCB未反映 |

V1の元データ、Gerber、作業中の変更は保持した。コピー元のSHA256は`hardware/v2-baseline-manifest.json`。これは製造時コミットのコピーではなく、2026-09-23時点の保存済み作業ファイルからの分岐である。V2にも旧PCBが残るため、PCBをそのまま発注しない。

## 追加: CAN端子（2026-09-23最終指定）

駆動V2/ODOM V2と中央の専用CANは横挿しJST GH3（1=COMM_A、2=COMM_B、3=GND）で統一する。同日のCAN2pin案は撤回。[一括発注計画](PCB_BATCH_V2_CENTRAL_PLAN.md)を参照。

## 2. V1課題とV2の受け入れ条件

| 優先度 | 課題 | V2の変更・完了条件 |
|---|---|---|
| P0 | デバッグ端子にVREFなし | MCUのデジタル3.3VレールをVTrefへ引き出し、ST-LINK表示とテスター値を照合できる |
| P0 | GH6で抜き差し・測定が困難 | 両基板で共通のキー付きSWD接続。UARTは独立3pinヘッダへ分離 |
| P0 | 向き・ピン番号が分かりにくい | 実装面視点のPin1三角、SWD表記、嵌合方向・ケーブルの抜き差し空間を確保。180°誤挿入を機械的に防ぐ |
| P0 | ODOMバッファ電源未接続 | U3/U7/U9 pin5=3.3V、pin2=GND。回路図・PCB・導通試験が一致する |
| P0 | その他のジャンパ・修正内容が散在 | 接続元/先・原因・回路図修正・PCB修正・実測結果を下表へ記録 |
| P0 | TP不足 | 電源、SWD、NRST、両CAN系統、センサ信号を実装後に測定可能にする |
| P0 | 一括実装後にしか異常を見つけられない | 電源→MCU/SWD→通信→センサの順で、外部負荷なしに検証できる |
| P1 | 実装時の型番/向き・LED極性取り違え | MCU型番/Pin1とLED A/Kを配置図・シルクで確認。回収品も型番を再照合 |
| P1 | 安価な部品の不足 | 確定BOMに実装必要数と手直し用予備を別記。抵抗・C・LED・コネクタは新品の共通在庫を用意 |
| P1 | 高価なICの回収 | MCU/TCAN/電源ICを回収候補とし、取り外し前後の動作・外観・短絡を確認して採否記録 |
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

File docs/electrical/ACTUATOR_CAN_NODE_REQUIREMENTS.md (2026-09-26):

# 24V Actuator CAN Node Rev.A requirements

> 2026-09-23変更: 中央とのCANはCOMM_A/COMM_B/GNDの3pin。コイルdriverを中央基板へ移す基本案のため、本文の折り取りCONTACTOR_DRIVERは次回発注の前提から外す。汎用スイッチング負荷は独立CANノードを維持し、今回PCB発注対象外。 詳細: [次回PCB一括発注計画](PCB_BATCH_V2_CENTRAL_PLAN.md)。

> **Status: Rev.A architecture fixed; human-review block diagram and preliminary BOM created (2026-09-17); pin-level human-review schematic `output/pdf/ACTUATOR_CAN_NODE_REV_A_SCHEMATIC_2026-09-17.pdf` created the same day. KiCad schematic not yet created.**
> This is the source of truth for the self-powered 12-24V CAN actuator node and its reusable contactor-driver edge block. The contactor block is installed at the central board, not operated across the CAN-node harness.
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

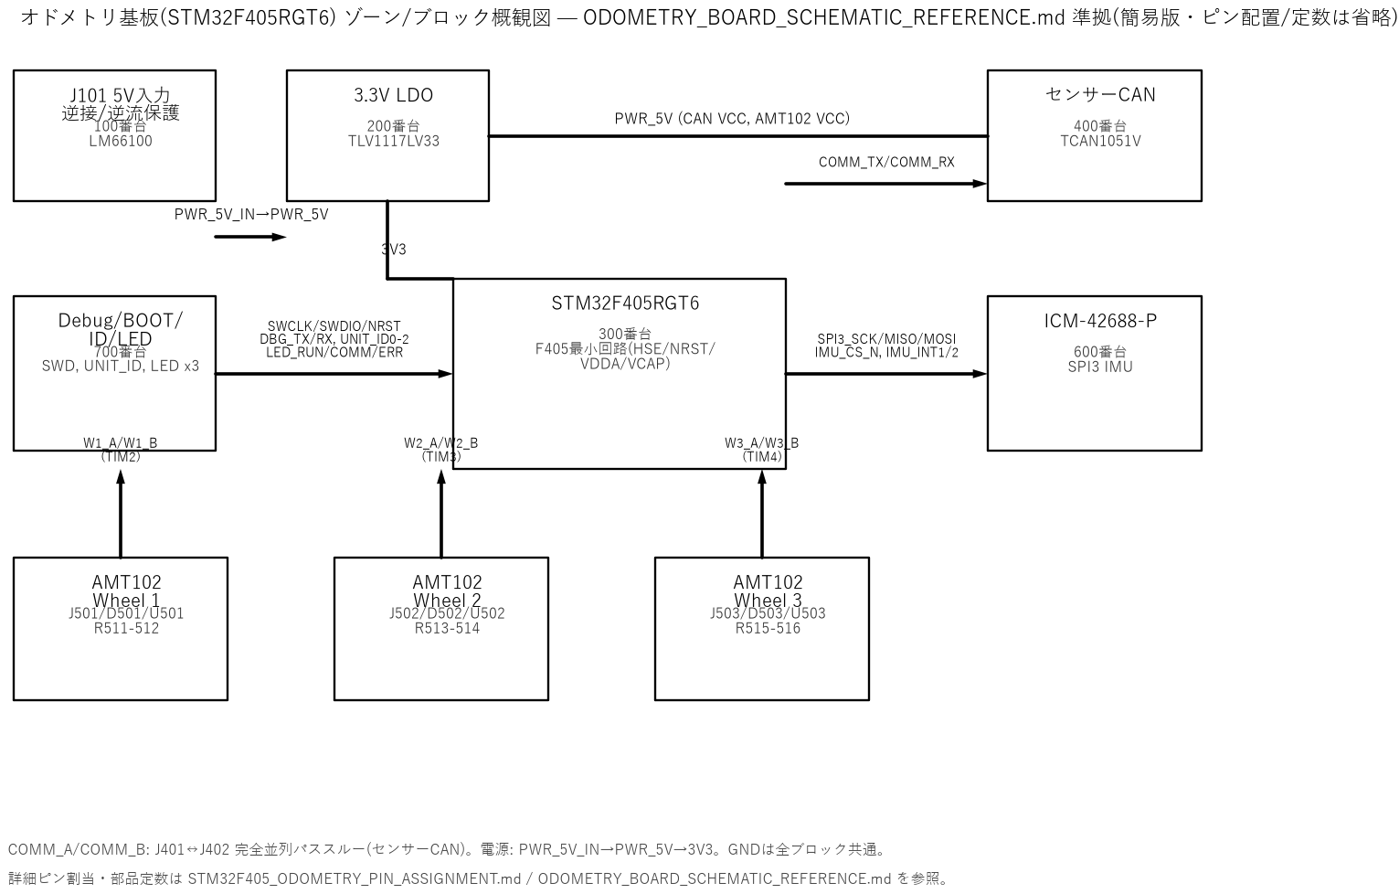
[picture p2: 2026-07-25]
docs/electrical/figures/odometry-board-overview.png

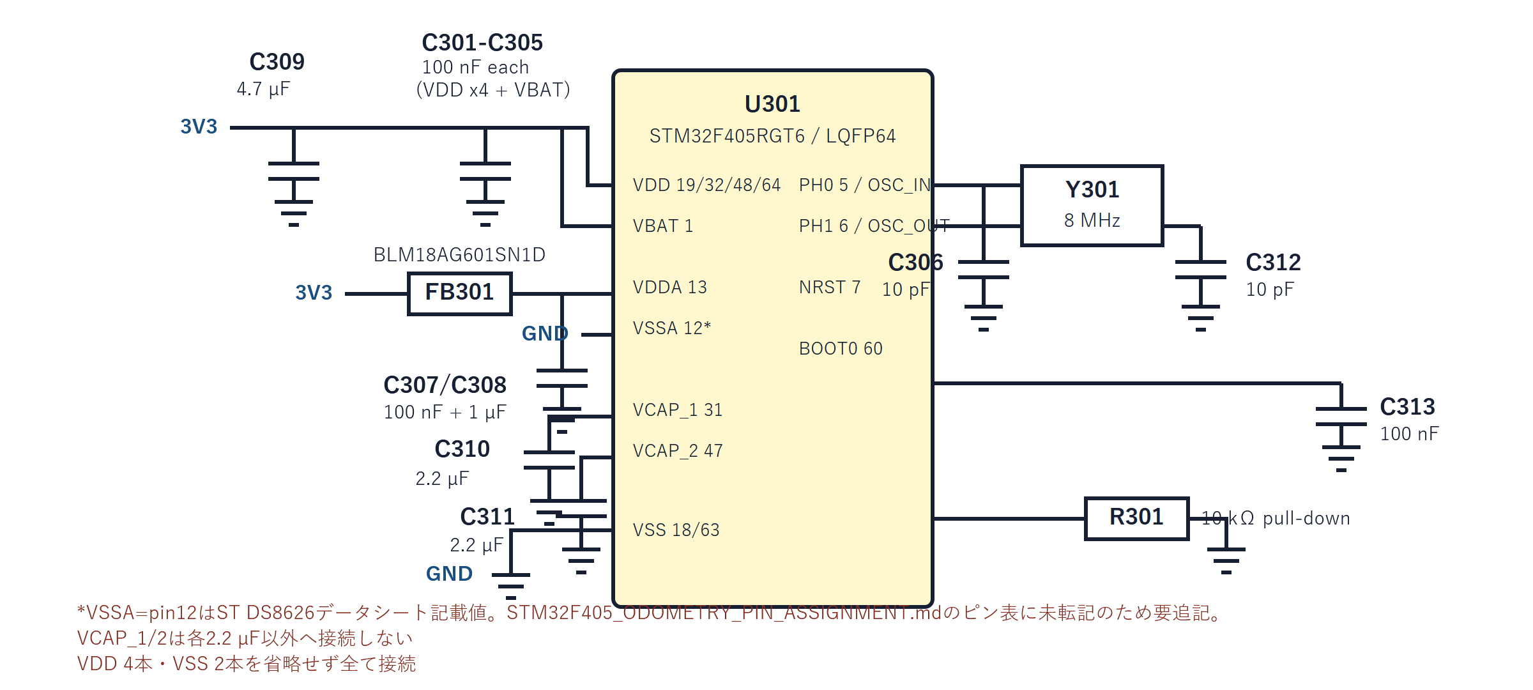
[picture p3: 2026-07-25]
docs/electrical/figures/odometry-board-f405.png

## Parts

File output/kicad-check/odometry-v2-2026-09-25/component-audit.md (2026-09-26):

# ODOM V2 component/layout audit (versioned saved-file snapshots)

## 2026-09-25 18:13 saved schematic update

The user saved the editor after the initial snapshot below. The new root schematic SHA-256 is `A2F4A7C09849111A95E8CE5AED9D5D15C15C3BAEF9B9A07A132F4DBBC034A9F9`. A fresh KiCad XML netlist export to `tmp/pdfs/odom_v2_latest_2026-09-25.xml` establishes:

- **The earlier J8/SWD vs J3/orphan finding is resolved in the newly saved schematic.** Root J3 is now `FTSH-105-01-L-DV-K-P`, symbol UUID `17446a2e-9e6d-48e0-80b5-f19b6ebbe132`, matching PCB J3 path. J8 is the CAN sheet's `BM03B-GHS-TBT(LF)(SN)`, UUID `752e8945-8ca7-475a-a6b2-e18d0bc2851a`, matching PCB J8 path. J9 UUID `179092da-efeb-49c3-aad8-b3258df33855` matches PCB J9.
- Latest schematic J3 pin nets: 1 `PWR_3.3V` (VTref), 2 SWDIO, 3/5/9 GND, 4 SWCLK, 6 SWO, 7/8 NC, 10 NRST. J9: 1 GND, 2 USART2_TX, 3 USART2_RX. U3/U7/U9: pin 2 GND and pin 5 `PWR_3.3V`.
- Latest schematic J3 is `(dnp no)`, while the saved PCB snapshot J3 is `(attr smd dnp)`; the PCB update should clear this assembly mismatch if J3 is to be fitted. The separate PCB repair agent is updating a candidate. The connector/cable pin-7 fit and local buffer decoupling findings below remain open until PCB placement and parts are reviewed.

The next section records the **earlier, pre-save** snapshot for traceability; its first J8/J3 mismatch is no longer current.

Read-only review on 2026-09-25 of `hardware/odometry-board-v2/Oddom board.kicad_pcb` (then last saved 2026-09-24 00:05:29; SHA-256 `E083D5B01C538ED794A6CB6537A5BC357CC32824D3408EF69E4FFA39D555C1C3`). The KiCad editor then contained unsaved changes. No PCB or schematic was edited for this review.

## Confirmed mismatches in the saved files

1. The current schematic calls **J8** the Cortex Debug 10-pin connector (root symbol UUID `dfcbf895-c956-4ade-92ed-07736ff78b6e`, blank footprint). The saved PCB's **J8** is a 3-pin JST GH CAN connector (`SamacSys:BM03BGHSTBTLFSN`): pad 1/2 are CAN TVS nets, pad 3 is GND, pads 4/5 are mechanical. The saved PCB's 10-pin SWD connector is instead **J3** (`SamacSys:FTSH10501LDVKP`, path `/17446a2e-9e6d-48e0-80b5-f19b6ebbe132`), whose path does not match the current schematic J8 UUID. This is an old-footprint/ref synchronization error, not evidence that the new J8 has been implemented.
2. PCB J3 is marked `(attr smd dnp)`. For the currently placed SWD header this means DNP in board data, so confirm desired assembly status when replacing/synchronizing it. Its saved pad nets are electrically in the intended order: 1 VTref (`PWR_3.3V`), 2 SWDIO, 3/5/9 GND, 4 SWCLK, 6 SWO, 7/8 NC, 10 NRST.

## Physical/layout review

- The saved J3 value/MPN is Samtec `FTSH-105-01-L-DV-K-P`. [Samtec's product page](https://www.samtec.com/products/ftsh-105-01-l-dv-k-p) confirms 10 contacts, 2 rows, 1.27 mm pitch, SMT, a keying notch, and a pick-and-place pad. Local footprint rows have 1.27 mm along-row pad pitch; the pin-1 silk dot is on the same end as pad 1. The SamacSys description says “Unshrouded,” whereas Samtec identifies the configured `-K` as a keying notch: use the exact manufacturer configuration and mating drawing for the final mechanical review. The footprint contains physical pad/pin 7 even though the Cortex/MIPI definition labels position 7 KEY/NC. A blocked-hole cable may not mate; exact cable/adapter and pin-7 mechanical treatment remain **unverified**, and a keying notch alone does not prove compatibility.
- UART J9 is present on saved PCB as `Connector_PinHeader_2.54mm:PinHeader_1x03_P2.54mm_Vertical`, with pin 1 GND at (88.985, 113.225), pin 2 `USART2_TX` at (91.525, 113.225), pin 3 `USART2_RX` at (94.065, 113.225) mm. It is on the board's lower edge. These pad nets match the 2026-09-23 [V2 requirement](../../../docs/electrical/UNIT_ODOMETRY_V2_REQUIREMENTS.md) and the current schematic J9 UUID `179092da-efeb-49c3-aad8-b3258df33855`. Its final pin-1/GND/TX/RX silkscreen readability and probe/cable access should be inspected at actual print scale.
- U3/U7/U9 `SN74LVC2G17DBVR` pad 2 is assigned GND and pad 5 is assigned `PWR_3.3V` in the saved PCB. Placement does **not** yet satisfy the stated “each IC nearby 100 nF” intent: nearest capacitor bridging 3.3 V/GND is C28 100 nF 18.29 mm from U3, C4 100 nF 16.91 mm from U7, and C8 100 nF 4.96 mm from U9 (footprint-center distances). U3/U7 have no local 100 nF within 8 mm. Add/relocate local decouplers in the schematic/placement phase and recheck actual rail routing; this is a design recommendation, not a change made in this audit.
- The saved U1 MCU's VDD/GND/VCAP pads have assigned nets; buffer power pins likewise have assigned nets. Net assignment alone does not establish copper connectivity. Detailed ERC/DRC, pad-to-net, and route checks are covered by the separate electrical audit.

## Review boundary

The current saved PCB still predates the in-editor save; all conclusions above describe that exact disk snapshot. Before release, compare the final chosen SWD header's manufacturer land pattern, its top/bottom and mating view, true pin 1, physical position 7, and the actual debugger cable against the completed PCB. The V2 requirements intentionally leave exact SWD connector/cable selection open.

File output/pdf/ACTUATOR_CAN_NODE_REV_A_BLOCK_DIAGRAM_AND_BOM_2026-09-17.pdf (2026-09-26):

S00 MOSスイッチング対応 CANノード - 設計サマリー | A3 landscape - human review drawing

HUMAN REVIEW ONLY - Rev.A architecture + preliminary BOM - not a fabrication release

# 12-24V補機をCANで安全にON/OFF・PWM制御するローカルノード

### 中央Teensyは高レベル指令のみ。負荷電流・PWM・タイムアウト処理はノード内で完結。

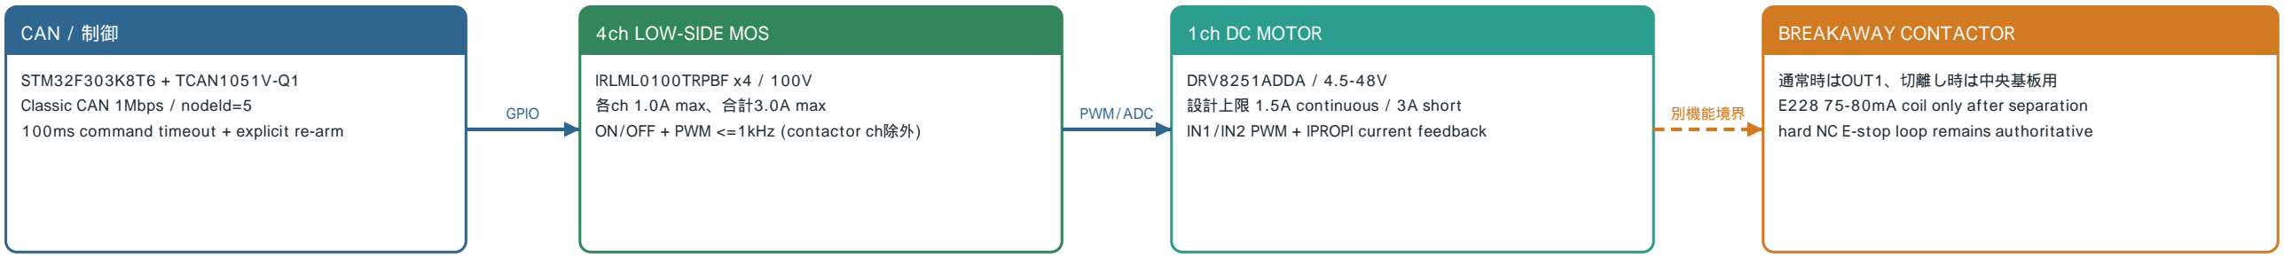
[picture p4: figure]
CAN / 制御; STM32F303K8T6 + TCAN1051V-Q1; Classic CAN 1Mbps / nodeId=5; 100ms command timeout + explicit re-arm; 4ch LOW-SIDE MOS; IRLML0100TRPBF x4 / 100V; 各ch 1.0A max、合計3.0A max; ON/OFF + PWM <=1kHz (contactor ch除外); 1ch DC MOTOR; DRV8251ADDA / 4.5-48V; 設計上限 1.5A continuous / 3A short; IN1/IN2 PWM + IPROPI current feedback; BREAKAWAY CONTACTOR; 通常時はOUT1、切離し時は中央基板用; E228 75-80mA coil only after separation; GPIO; PWM/ADC; 別機能境界

hard NC E-stop loop remains authoritative

[FIXED] この基板で扱わないもの

C620、走行モータ主電流、回生ブレーキ、プリチャージ、LEDテープの画素波形。E-stop一次経路もCANに依存させない。

[FIXED] 電源境界

VIN_ACT=9-30V動作域、6S最大25.2V。アクチュエータ電流は中央基板を通さず、外部ヒューズ付き枝線から供給。

[CHECK] 最大定格ではなく設計上限

MOS 1A/ch・3A合計、H bridge
1.5A連続は初版の熱設計上限。実負荷の突入・stall測定前に増やさない。

## Rev.Aで必ず止める故障

### OUTPUT OFF

CAN指令が100ms途絶

### OUTPUT OFF

watchdog / MCU reset / brownout

### OUTPUT OFF

中央ESTOP broadcast

### OUTPUT OFF

DRV8251内部UVLO/OCP/TSD

FIXED | PROPOSAL | CHECK | STOP
Differential Swerve / 24V Actuator CAN Node Rev.A / 2026-09-17 | S00 Node ID=5 / Classic CAN 1Mbps

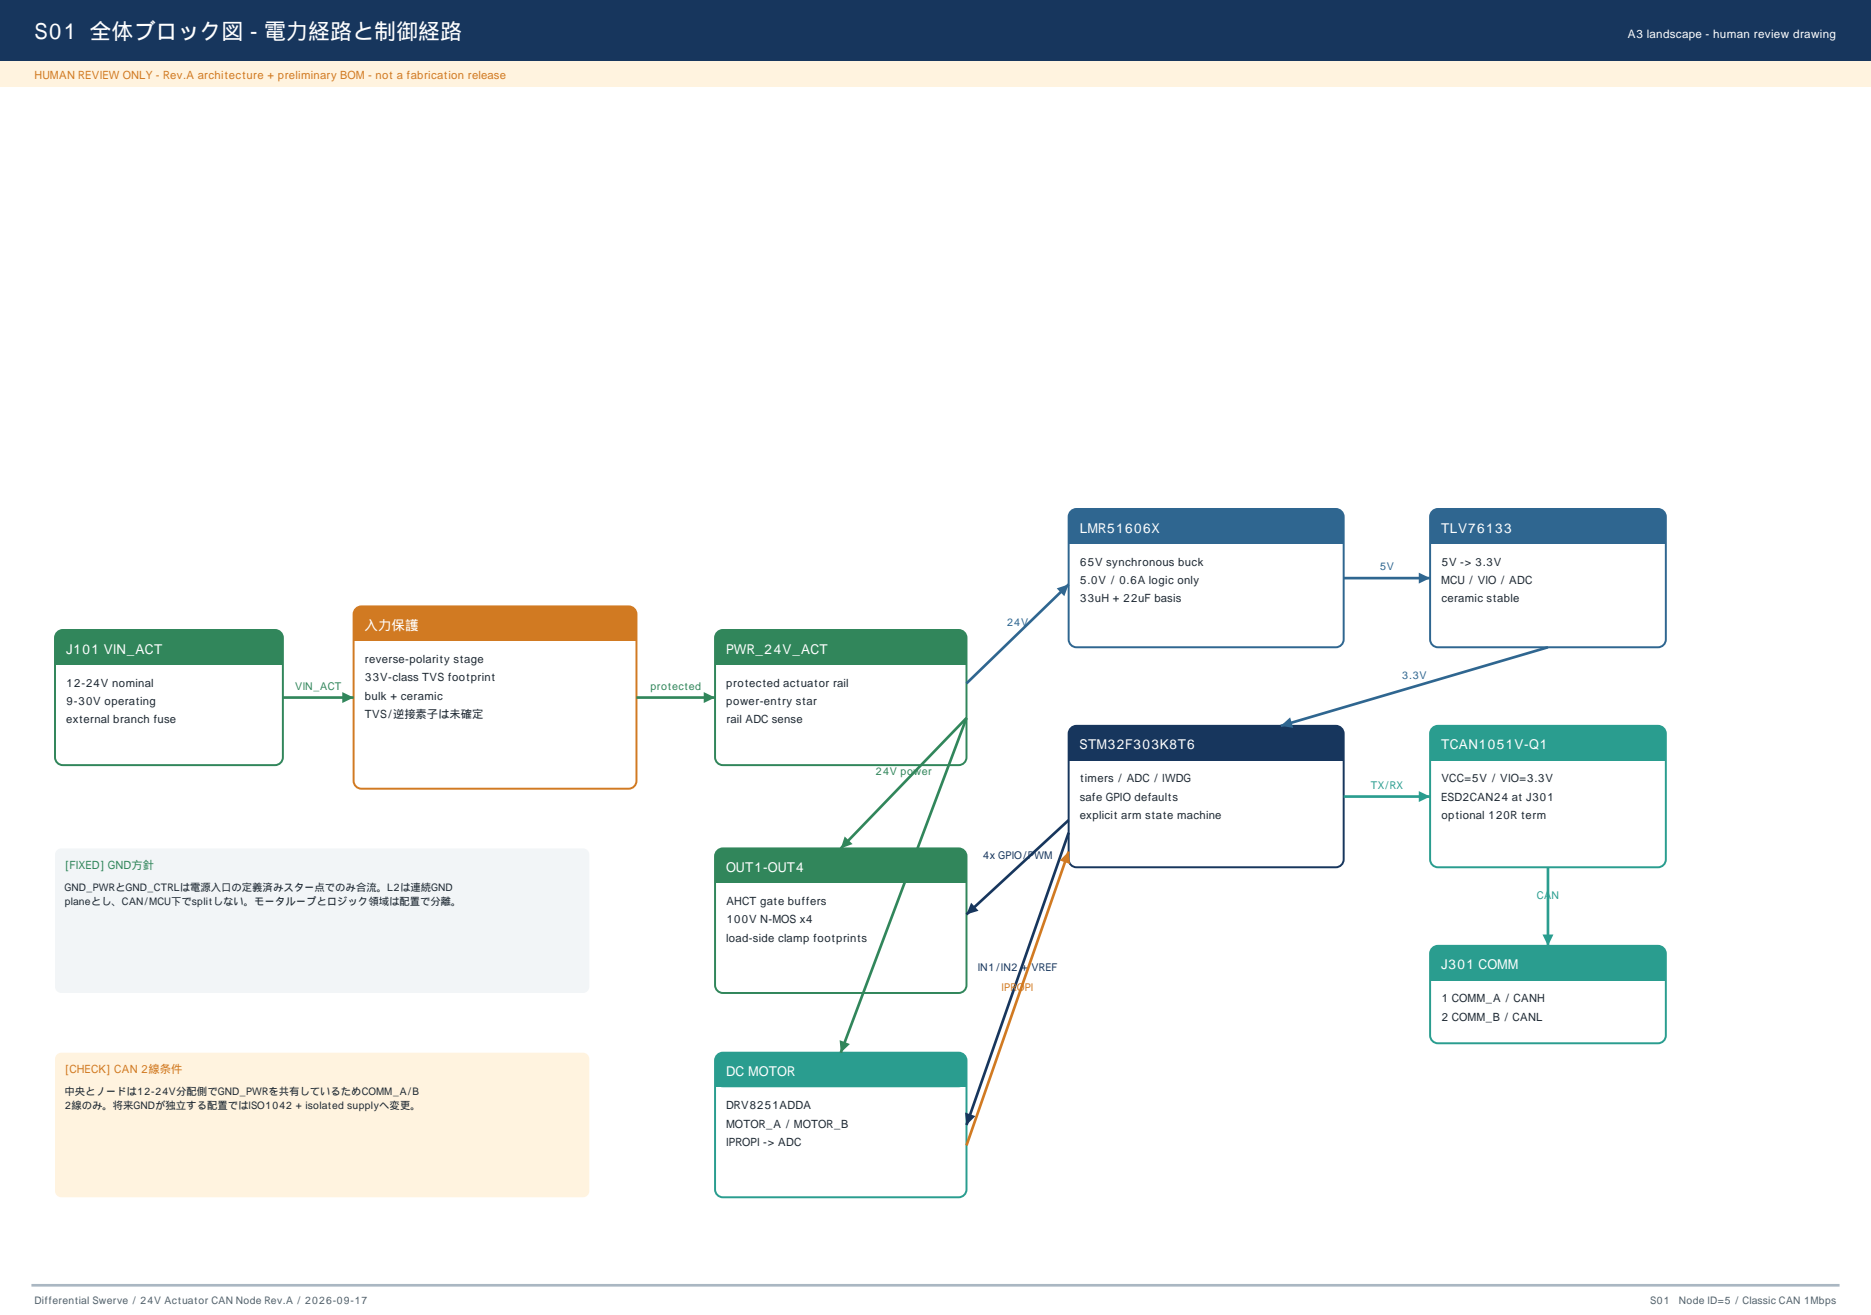
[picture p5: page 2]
S01 全体ブロック図 - 電力経路と制御経路; A3 landscape - human review drawing; J101 VIN_ACT; 入力保護; PWR_24V_ACT; VIN_ACT; protected; LMR51606X; 65V synchronous buck; 5.0V / 0.6A logic only; 33uH + 22uF basis; TLV76133; STM32F303K8T6; TCAN1051V-Q1; VCC=5V / VIO=3.3V; ESD2CAN24 at J301; optional 120R term; J301 COMM; 1 COMM_A / CANH; 2 COMM_B / CANL; CAN; OUT1-OUT4; DC MOTOR; DRV8251ADDA; MOTOR_A / MOTOR_B; IPROPI -> ADC; 24V power; 4x GPIO/PWM; IN1/IN2 + VREF; IPROPI; [FIXED] GND方針; [CHECK] CAN 2線条件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

MCU / VIO / ADC
ceramic stable

reverse-polarity stage
33V-class TVS footprint
bulk + ceramic
TVS/逆接素子は未確定

12-24V nominal
9-30V operating
external branch fuse

protected actuator rail
power-entry star
rail ADC sense

timers / ADC / IWDG
safe GPIO defaults
explicit arm state machine

GND_PWRとGND_CTRLは電源入口の定義済みスター点でのみ合流。L2は連続GND
planeとし、CAN/MCU下でsplitしない。モータループとロジック領域は配置で分離。

AHCT gate buffers
100V N-MOS x4
load-side clamp footprints

S02 入力保護、ローカル電源、GND/配線境界 | A3 landscape - human review drawing

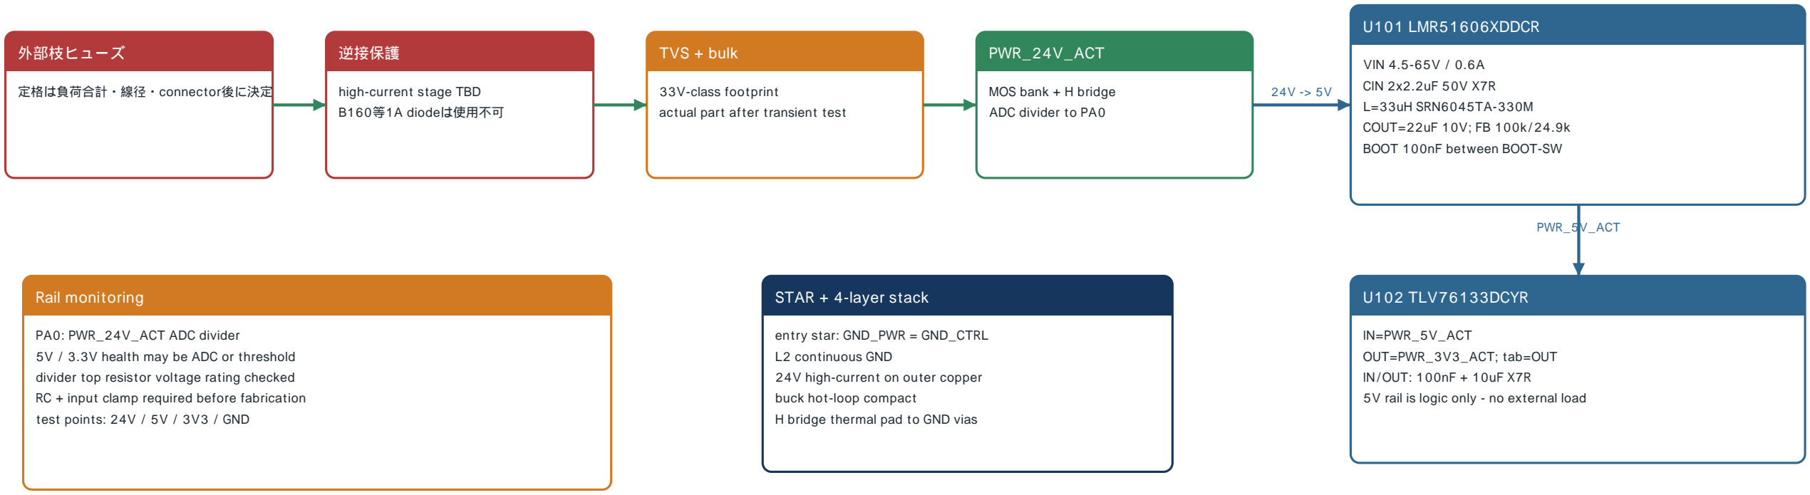
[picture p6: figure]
外部枝ヒューズ; 定格は負荷合計・線径・connector後に決定; 逆接保護; high-current stage TBD; B160等1A diodeは使用不可; TVS + bulk; 33V-class footprint; actual part after transient test; PWR_24V_ACT; MOS bank + H bridge; ADC divider to PA0; U101 LMR51606XDDCR; VIN 4.5-65V / 0.6A; CIN 2x2.2uF 50V X7R; L=33uH SRN6045TA-330M; COUT=22uF 10V; FB 100k/24.9k; BOOT 100nF between BOOT-SW; U102 TLV76133DCYR; IN=PWR_5V_ACT; OUT=PWR_3V3_ACT; tab=OUT; IN/OUT: 100nF + 10uF X7R; PWR_5V_ACT; STAR + 4-layer stack; entry star: GND_PWR = GND_CTRL; L2 continuous GND; 24V high-current on outer copper; buck hot-loop compact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

5V rail is logic only - no external load

5V / 3.3V health may be ADC or threshold divider top resistor voltage rating checked RC + input clamp required before fabrication

[STOP] 入力TVS

ハーネス実測前は特定MPNをBOM確定しない。stand-offだけでなくclamp voltage、pulse energy、buck 65V abs maxとの整合で決める。

[STOP] 逆接保護

アクチュエータ合計電流を流すため、LEDノードの1A直列Schottkyを流用しない。MOS ideal-diode又は定格十分な直列素子を選定。

[STOP] 外部ヒューズ

基板入力、各負荷、モータの保護協調を負荷実測後に決定。PCBパターンやconnector定格より大きいヒューズを付けない。

Differential Swerve / 24V Actuator CAN Node Rev.A / 2026-09-17 | S02 Node ID=5 / Classic CAN 1Mbps

S03 MCU、CAN、service、安全状態機械 | A3 landscape - human review drawing

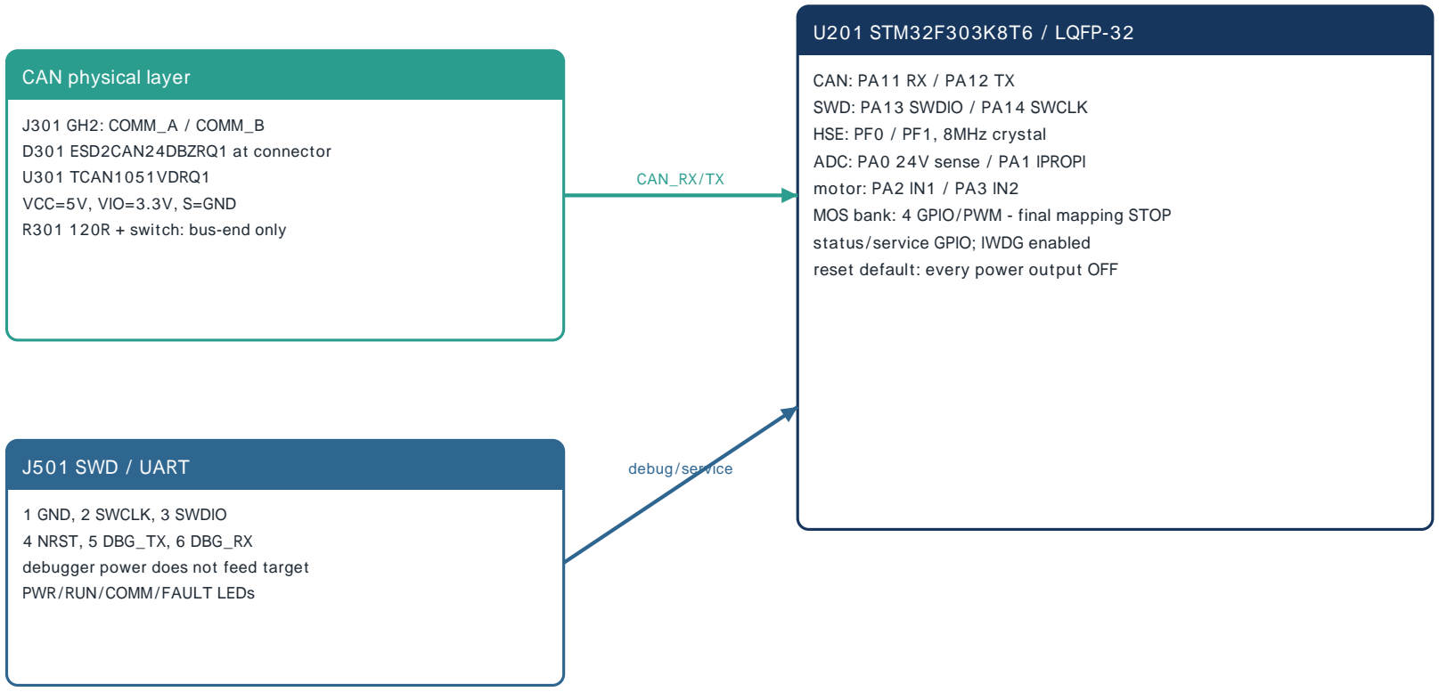
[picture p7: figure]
U201 STM32F303K8T6 / LQFP-32; CAN: PA11 RX / PA12 TX; SWD: PA13 SWDIO / PA14 SWCLK; HSE: PF0 / PF1, 8MHz crystal; ADC: PA0 24V sense / PA1 IPROPI; motor: PA2 IN1 / PA3 IN2; status/service GPIO; IWDG enabled; reset default: every power output OFF; CAN physical layer; J301 GH2: COMM_A / COMM_B; D301 ESD2CAN24DBZRQ1 at connector; U301 TCAN1051VDRQ1; VCC=5V, VIO=3.3V, S=GND; R301 120R + switch: bus-end only; CAN_RX/TX; J501 SWD / UART; 1 GND, 2 SWCLK, 3 SWDIO; 4 NRST, 5 DBG_TX, 6 DBG_RX; debugger power does not feed target; PWR/RUN/COMM/FAULT LEDs; debug/service

MOS bank: 4 GPIO/PWM - final mapping STOP

### BOOT / SELF TEST

outputs disabled
rail + CAN + motor input sanity wait explicit ACTUATOR_ARM

### ARMED

accept fresh sequence
apply OUT bitmap/PWM + motor command publish ACTUATOR_STATUS

### FAULT LATCH / OFF

all MOS low; motor coast/Hi-Z traffic recovery does not auto-restart new explicit re-arm required

self-test OK + ARM

fault/timeout/ESTOP | clear + explicit re-arm

[STOP] DRV8251A端子訂正

DRV8251ADDAにはnFAULT端子がない。Rev.Aの直接観測はIPROPIのみ。UVLO/OCP/TSDはIC内部保護として動作するが、個別fault pinとしてMCUへは返らない。

Differential Swerve / 24V Actuator CAN Node Rev.A / 2026-09-17 | S03 Node ID=5 / Classic CAN 1Mbps

S04 OUT1-OUT4 - 100V low-side MOS switching | A3 landscape - human review drawing

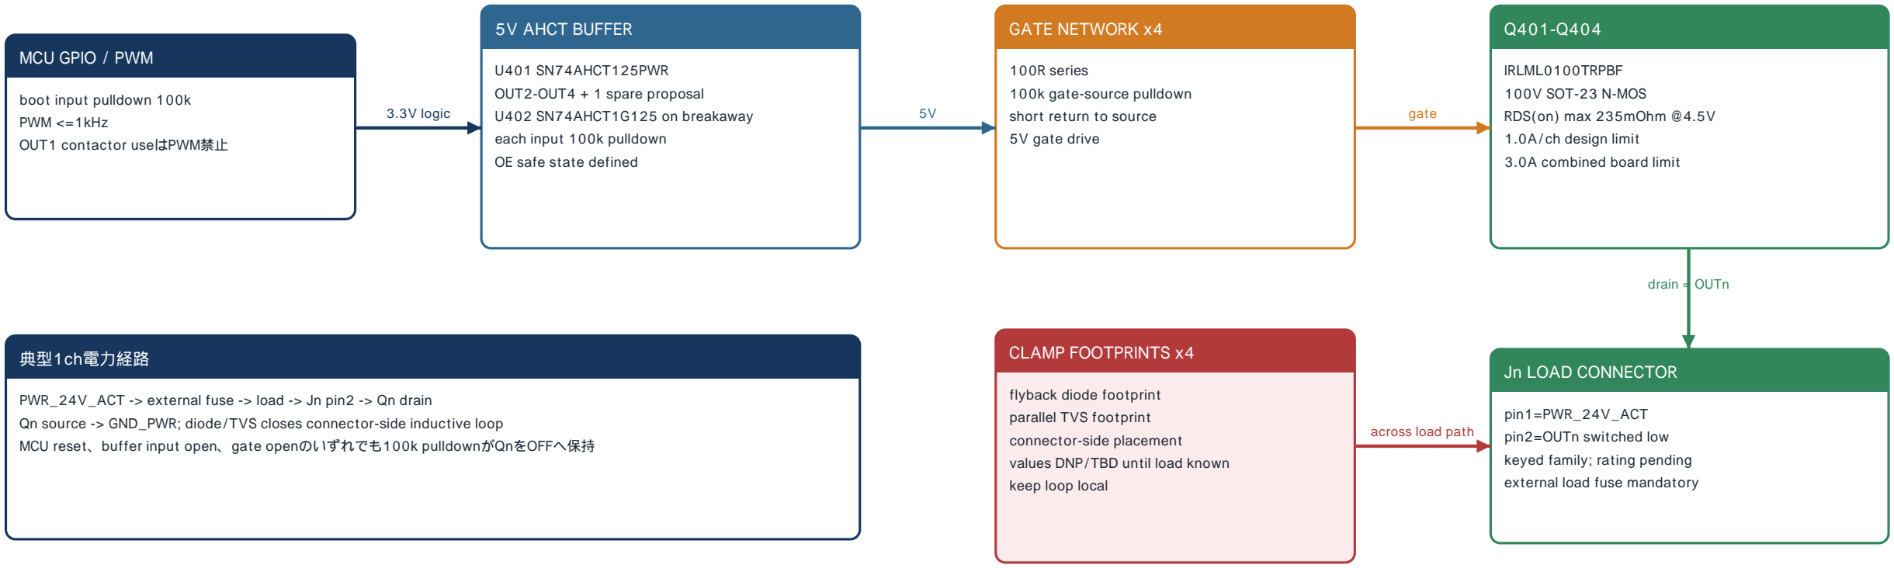
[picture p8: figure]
MCU GPIO / PWM; boot input pulldown 100k; PWM <=1kHz; OUT1 contactor useはPWM禁止; 5V AHCT BUFFER; U401 SN74AHCT125PWR; OUT2-OUT4 + 1 spare proposal; U402 SN74AHCT1G125 on breakaway; each input 100k pulldown; OE safe state defined; GATE NETWORK x4; 100R series; 100k gate-source pulldown; short return to source; 5V gate drive; IRLML0100TRPBF; 100V SOT-23 N-MOS; RDS(on) max 235mOhm @4.5V; 1.0A/ch design limit; 3.0A combined board limit; 3.3V logic; gate; Jn LOAD CONNECTOR; pin1=PWR_24V_ACT; pin2=OUTn switched low; keyed family; rating pending; external load fuse mandatory; drain = OUTn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

PWR_24V_ACT -> external fuse -> load -> Jn pin2 -> Qn drain
Qn source -> GND_PWR; diode/TVS closes connector-side inductive loop
MCU reset、buffer input open、gate openのいずれでも100k pulldownがQnをOFFへ保持

[CHECK] 熱設計

1A時のMOS損失目安はRDS(on)最大値で約0.235W。銅面・周囲温度・4ch同時率を含め実測する。

[STOP] 誘導負荷

diodeは低サージだがreleaseが遅い。TVSは速いがVDS stressが増える。負荷ごとに波形を測り、100V margin内で選定。

[STOP] GPIO割当

正本内でPA5 contactorとPA6-PB1
OUT1-4が重複。OUT1=breakawayを維持した最終4ch mappingをKiCad前に確定。
Differential Swerve / 24V Actuator CAN Node Rev.A / 2026-09-17 | S04 Node ID=5 / Classic CAN 1Mbps

S05 DRV8251A H bridge + 分離式CONTACTOR_DRIVER | A3 landscape - human review drawing

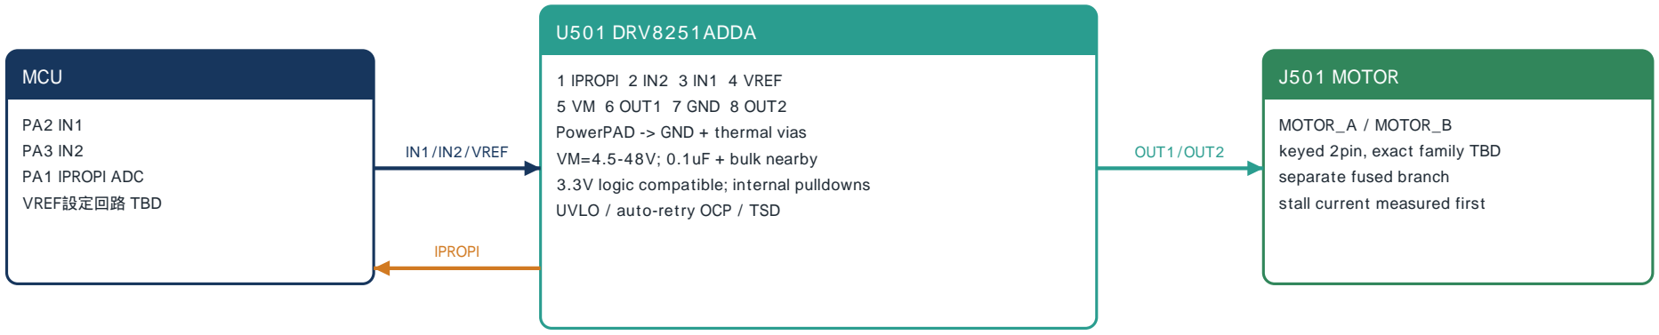
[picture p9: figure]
MCU; PA1 IPROPI ADC; VREF設定回路 TBD; U501 DRV8251ADDA; 1 IPROPI 2 IN2 3 IN1 4 VREF; 5 VM 6 OUT1 7 GND 8 OUT2; PowerPAD -> GND + thermal vias; VM=4.5-48V; 0.1uF + bulk nearby; 3.3V logic compatible; internal pulldowns; UVLO / auto-retry OCP / TSD; J501 MOTOR; MOTOR_A / MOTOR_B; keyed 2pin, exact family TBD; separate fused branch; stall current measured first; IN1/IN2/VREF; OUT1/OUT2; IPROPI

[FIXED] H bridge限界

24V brushed DC motorのみ。1.5A continuous / 3A short-pulseは基板設計上限。ICの4.1A peak protection値を連続定格として使わない。

MOUSE-BITE / TAB CUT LINE - 下側ブロックを切離したときだけ中央基板用contactor driver

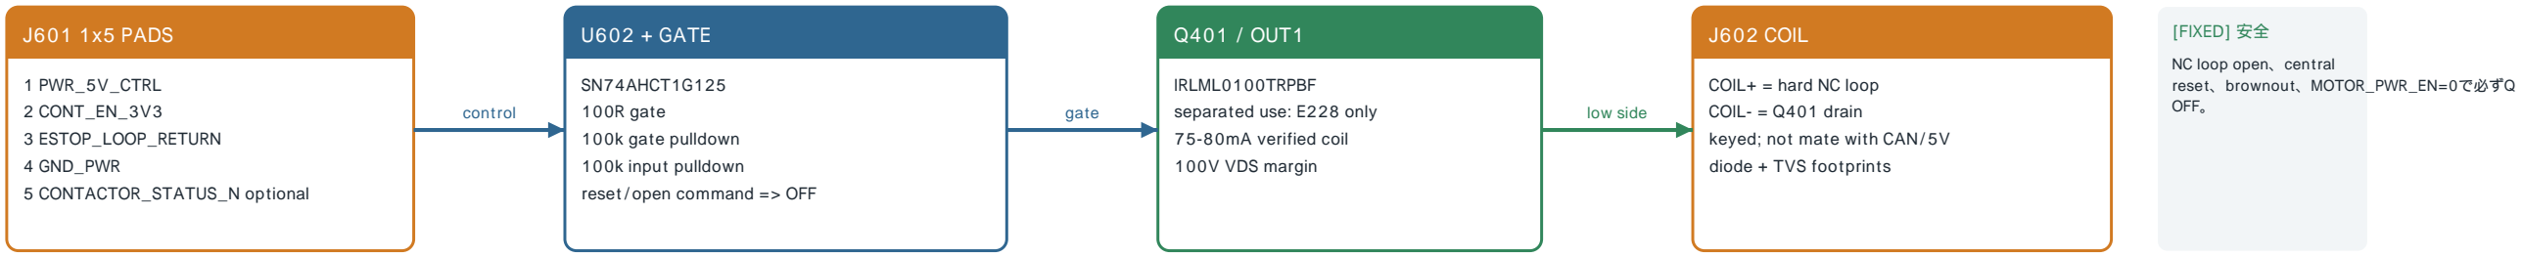
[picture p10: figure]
J601 1x5 PADS; 1 PWR_5V_CTRL; 2 CONT_EN_3V3; 3 ESTOP_LOOP_RETURN; 4 GND_PWR; 5 CONTACTOR_STATUS_N optional; U602 + GATE; SN74AHCT1G125; 100R gate; 100k gate pulldown; 100k input pulldown; reset/open command => OFF; Q401 / OUT1; IRLML0100TRPBF; separated use: E228 only; 75-80mA verified coil; 100V VDS margin; J602 COIL; COIL+ = hard NC loop; COIL- = Q401 drain; keyed; not mate with CAN/5V; diode + TVS footprints; control; gate; low side; [FIXED] 安全; NC loop open、central reset、brownout、MOTOR_PWR_EN=0で必ずQ; OFF。

Differential Swerve / 24V Actuator CAN Node Rev.A / 2026-09-17 | S05 Node ID=5 / Classic CAN 1Mbps

B01 暫定BOM 1/2 - 電源、MCU、CAN | A3 landscape - human review drawing
Refs | Qty | Function | Manufacturer / MPN or value | Package | Status / note
J101 | | node power input | 2-pin keyed power connector, >=8A target | TBD | STOP: exact family/current derating
FEXT | | external branch fuse | fuse + holder sized after load audit | off-board | STOP: rating pending
Q/D101 | | reverse polarity | high-current MOS ideal-diode or rated series device | TBD | STOP: select by current/transient
D102 | | input surge clamp | 33V-class TVS | SMB/SMC TBD | STOP: waveform/energy pending
U101 | | 24V to 5V buck | Texas Instruments LMR51606XDDCR | SOT-23-6 DBV | FIXED
L101 | | buck inductor | Bourns SRN6045TA-330M, 33uH | 6x6mm SMD | FIXED
C101,C102 | | buck input | 2.2uF 50V X7R | 1206 | FIXED; DC-bias check
C103 | | bootstrap | 100nF 16V X7R | 0603 | FIXED; BOOT-SW
C104 | | buck output | 22uF 10V X7R | 1206 | FIXED; DC-bias check
R101,R102 | | buck feedback | 100k / 24.9k, 1% | 0603 | FIXED; nominal 5.0V
U102 | | 5V to 3.3V LDO | Texas Instruments TLV76133DCYR | SOT-223, tab=OUT | FIXED
C111-C114 | | LDO bypass | 100nF x2 + 10uF x2, X7R | 0603 / 0805 | FIXED
U201 | | MCU | ST STM32F303K8T6 | LQFP-32 | FIXED
Y201 | | 8MHz HSE | FC3BAEBDI8.0-T1, CL=8pF | 3225 4-pad | FIXED
C201,C202 | | HSE load | 10pF C0G | 0603 | FIXED; verify stray C
FB201 | | analog rail bead | Murata BLM18AG601SN1D | 0603 | FIXED/project common
C2xx | | MCU/analog decoupling | 100nF x4, 1uF x2, 10nF x1, reset 100nF | 0603 | FIXED group; final refs in KiCad
J501 | | SWD/UART | JST BM06B-GHS-TBT | GH 6-pin vertical | FIXED/project convention
U301 | | CAN transceiver | Texas Instruments TCAN1051VDRQ1 | SOIC-8 | FIXED
D301 | | CAN ESD | Texas Instruments ESD2CAN24DBZRQ1 | SOT-23-3 | FIXED
J301 | | CAN connector | JST SM02B-GHS-TB | GH 2-pin SMT | FIXED; 1=A, 2=B
R301,SW301 | 1+1 | optional termination | 120R 1% + JS102011SAQN | 0603 + slide | DNP unless physical bus end
LED/R | 4+4 | PWR/RUN/COMM/FAULT | LED 0603 + series resistor | 0603 | PROPOSAL: color/value at schematic
TP | | test points | 24V, 5V, 3V3, GND, COMM_A, COMM_B | SMD loop/pad | FIXED function

数量は基板1枚あたり。外部ヒューズ・相手側housing/contact・実装予備は含まない。

Differential Swerve / 24V Actuator CAN Node Rev.A / 2026-09-17 | B01 Node ID=5 / Classic CAN 1Mbps

B02 暫定BOM 2/2 - MOS出力、H bridge、breakaway | A3 landscape - human review drawing
Refs | Qty | Function | Manufacturer / MPN or value | Package | Status / note
U401 | | OUT2-OUT4 gate buffer | Texas Instruments SN74AHCT125PWR | TSSOP-14 | PROPOSAL: 3 used + 1 spare
U402 | | OUT1/breakaway buffer | Texas Instruments SN74AHCT1G125DCKR | SC70-5 | PROPOSAL: stays on tab
Q401-Q404 | | low-side switch | Infineon IRLML0100TRPBF, 100V | SOT-23 | FIXED; 1A/ch design limit
RG401-RG404 | | gate series | 100R, 1% | 0603 | FIXED
RGS401-RGS404 | | gate pulldown | 100k, 1% | 0603 | FIXED
RIN401-RIN404 | | buffer input pulldown | 100k, 1% | 0603 | FIXED
C401,C402 | | buffer bypass | 100nF X7R | 0603 | FIXED
D401-D404 | | flyback diode footprints | load-specific diode | TBD footprint | DNP/STOP: load waveform pending
TVS401-TVS404 | | fast release clamps | load-specific TVS | TBD footprint | DNP/STOP: Vclamp pending
J401-J404 | | 24V load outputs | keyed 2-pin >=1A/channel | TBD | STOP: exact connector/fuse
U501 | | brushed motor H bridge | Texas Instruments DRV8251ADDA | HSOP-8 PowerPAD | FIXED; no nFAULT pin
C501 | | VM ceramic bypass | 100nF >=50V X7R | 0603/0805 | FIXED; at VM-GND
C502 | | motor local bulk | low-ESR electrolytic/polymer >=50V | TBD | STOP: capacitance/ripple pending
RIPROPI | | current mirror resistor | value set from current range/ADC | 0603 | STOP: calculate from DS
VREF net | 2-3 | current regulation threshold | divider/DAC/filter as selected | 0603 | STOP: topology/value pending
J501M | | motor output | keyed 2-pin >=1.5A cont / 3A pulse | TBD | STOP: exact family/thermal
J601A/B | | breakaway interface pads | 2.54mm 1x5 unpopulated through-hole | THT pads | FIXED; normally no header
J602 | | E228 coil connector | keyed 2-pin, incompatible with CAN/5V | TBD | STOP: exact family
D601 | | E228 safe flyback | diode sized for 24V/80mA coil | TBD | PROPOSAL for first test
TVS601 | | E228 fast release | parallel TVS footprint | TBD | DNP/STOP: waveform pending
RADC/CADC | 3-5 | 24V/IPROPI ADC conditioning | divider + RC + clamp network | 0603 | STOP: exact values/protection
PCB | | board | 4-layer, outer 1oz minimum, L2 solid GND | mouse-bite edge tab | FIXED architecture

[CHECK] BOMの意味

FIXEDは採用品、PROPOSALは回路分割案、DNP/STOPはfootprint候補を置いても実装・発注確定しない。価格・在庫は未調査。

[STOP] 不足している設計値

入力逆接/TVS、各負荷clamp、motor bulk、RIPROPI/VREF、全power connector/fuseは実負荷とハーネス測定後に確定する。

Differential Swerve / 24V Actuator CAN Node Rev.A / 2026-09-17 | B02 Node ID=5 / Classic CAN 1Mbps

R01 リリースゲート、既知の不整合、データシート根拠 | A3 landscape - human review drawing

## KiCad着手前に閉じるSTOP項目

1. DRV8251AにnFAULT pinはない。status/protocol/firmwareのfault表現をIPROPI + inferred protectionへ修正するか、nFAULT必須ならdriverを再選定。
2. OUT1=breakawayという境界と、PA5 contactor / PA6-PA7-PB0-PB1 OUT1-4というGPIO割当重複を解消。4 MOS総数は維持。
3. VIN_ACT入力connector、reverse-polarity素子、外部branch fuseを最大同時負荷・wire gauge・温度で選定。
4. input TVSは実ハーネスtransientを測定し、33V stand-off / clamp energy / 65V buck limitで確定。
5. 4出力それぞれの実負荷を確定し、flyback diode / TVS / fuse / connectorを個別選定。
6. 使用DC motorのstall currentを測り、RIPROPI、VREF、bulk capacitor、connectorを計算。
7. CAN topologyを確認し、120R terminationは物理bus endだけ実装。
8. mouse-bite加工ルール、tab copper bridge、切離し後clearanceを基板業者仕様で確認。

## Bring-up順序

5V current-limited input: 3.3V, reset defaults, SWD, CAN, watchdog, every gate OFF.

24V no-load: input transient/rail ADC, buck temperature, DRV8251 state, CAN timeout.

Resistive load: 0.25A -> 0.5A -> 1.0A/ch, single then combined, record MOS/connector/copper temperature.

Inductive loads: capture Q VDS and release time; populate diode/TVS only from measured requirement.

Motor: measured stall current, current-limited source/fuse, direction/PWM/coast/brake, IPROPI and thermal test.

Separated contactor tab: dummy 24V/80mA then E228; open each NC, reset/brownout, record release waveform.

KiCad ERC=0, PCB DRC=0, netlist-to-pin-table review, then fabrication release.

### Primary data sheets checked

ST DS9866 Rev.8 - STM32F303x6/x8; CAN 2.0B, LQFP-32 pin functions.

TI LMR51606 SLUSEY1B - 4.5-65V, 0.6A; 400kHz X variant application values.

TI DRV8251A SLVSFU6 - 4.5-48V, 4.1A peak, HSOP-8 pinout, IPROPI; no nFAULT pin.

TI TCAN1051-Q1 Rev.D / ESD2CAN24-Q1 Rev.D / TLV761 Rev.D / SN74AHCT125 Rev.R.

Infineon IRLML0100 - 100V SOT-23; RDS(on) max 235mOhm at VGS=4.5V.

Differential Swerve / 24V Actuator CAN Node Rev.A / 2026-09-17 | R01 Node ID=5 / Classic CAN 1Mbps

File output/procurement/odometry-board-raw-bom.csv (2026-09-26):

Refs | Value | Footprint | Qty | DNP
C1 | 2.2uF | Capacitor_SMD:C_0805_2012Metric | 1
C2,C4,C8,C9,C11-C14,C18,C19,C22,C28 | 100nF | Capacitor_SMD:C_0603_1608Metric | 12
C3,C5 | 10uF | Capacitor_SMD:C_0805_2012Metric | 2
C6,C7 | 10pF | Capacitor_SMD:C_0603_1608Metric | 2
C10 | 4.7uF | Capacitor_SMD:C_0805_2012Metric | 1
C15,C17,C23-C26 | DNP | Capacitor_SMD:C_0603_1608Metric | 6
C16 | 1uF | Capacitor_SMD:C_0603_1608Metric | 1
C20,C21,C27 | 2.2 µF | Capacitor_SMD:C_0805_2012Metric | 3
D1 | ESD2CAN24DBZRQ1 | Package_TO_SOT_SMD:SOT-23 | 1
D2-D4 | D_TVS_Dual_AACESDS452DBZ | Package_TO_SOT_SMD:SOT-23 | 3
D6,D8 | LTST-C190KGKT | LED_SMD:LED_0603_1608Metric | 2
D9 | LTST-C190KSKT | LED_SMD:LED_0603_1608Metric | 1
D10 | LTST-C190KRKT | LED_SMD:LED_0603_1608Metric | 1
FB1 | BLM18AG601SN1D | Inductor_SMD:L_0603_1608Metric | 1
J1 | SM02B-GHS-TB | Connector_JST:JST_GH_SM02B-GHS-TB_1x02-1MP_P1.25mm_Horizontal | 1
J2 | SM03B-GHS-TB | Connector_JST:JST_GH_SM03B-GHS-TB_1x03-1MP_P1.25mm_Horizontal | 1
J4-J6 | Conn_01x04 | Connector_JST:JST_XH_B4B-XH-AM_1x04_P2.50mm_Vertical | 3
J7 | Conn_01x08 | Connector_JST:JST_XH_B8B-XH-AM_1x08_P2.50mm_Vertical | 1
J8 | BM06B-GHS-TBT | Connector_JST:JST_GH_BM06B-GHS-TBT_1x06-1MP_P1.25mm_Vertical | 1
R1 | 120R | Resistor_SMD:R_0603_1608Metric | 1
R2,R5-R9 | 100R | Resistor_SMD:R_0603_1608Metric | 6
R3 | RC0603JR-070RL 0R | Resistor_SMD:R_0603_1608Metric | 1
R4 | RC0603FR-0710KL 10k | Resistor_SMD:R_0603_1608Metric | 1
R19-R22 | 1k | Resistor_SMD:R_0603_1608Metric | 4
SW1 | JS102011SAQN | DifferentialSwerve:JS102011SAQN | 1
SW3 | A6S-3104-H | Button_Switch_SMD:SW_DIP_SPSTx03_Slide_Omron_A6S-310x_W8.9mm_P2.54mm | 1
U1 | STM32F405RGTx | Package_QFP:LQFP-64_10x10mm_P0.5mm | 1
U2 | TLV1117LV33DCYR | Package_TO_SOT_SMD:SOT-223-3_TabPin2 | 1
U3,U7,U9 | 74LVC2G17 | Package_TO_SOT_SMD:SOT-23-6 | 3
U4 | TCAN1051VDRQ1 | Package_SO:SOIC-8_3.9x4.9mm_P1.27mm | 1
U5 | LM66100DCKR | Package_TO_SOT_SMD:SOT-363_SC-70-6 | 1
Y1 | ECS-80-8-33Q-JES-TR | Crystal:Crystal_SMD_3225-4Pin_3.2x2.5mm | 1

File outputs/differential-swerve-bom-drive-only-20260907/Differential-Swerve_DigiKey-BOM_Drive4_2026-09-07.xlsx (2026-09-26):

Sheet: サマリー
Differential Swerve — 駆動基板 DigiKey調達サマリー
価格・在庫確認日 | 2026-09-07 (JST)
今回の発注対象 | 駆動モジュール基板 4枚（実機3＋丸ごと予備1）。ODOM基板は発注済み
購入行数 | 27
税抜部品概算 | ¥11617.60
消費税10%参考 | ¥1161.76
税込概算 | ¥12779.36
送料 | DigiKey通常商品6,000円以上のため無料見込み（確定はカート）
欠品行 | 1
重要 | 対象 | 状態 | 対応
要確認 | SM03B-GHS-TB | 欠品/繰越注文 | DigiKeyカートで入荷日を確認。代替はフットプリントが変わるため未採用
置換済 | 1uF / 10nF C0G / BAT54S / LDO / DIP / 水晶 | 在庫品へ変更 | 容量・定格・誘電体・外形またはpin配置を照合済み
発注済み | ODOM基板1枚分 | 今回の購入数は0 | 内訳シートは組立確認用として残す
手持ち | GHコネクタ | 2極横・6極横・6極垂直 | SM02B、SM06B、BM06BをDigiKey発注から除外
使い方 | 1 | 統合発注BOMのオレンジ行（SM03）の納期をカートで確認
 | 2 | CSVをDigiKey BOM Managerへアップロード
 | 3 | 税込概算・在庫・価格を最終確認して発注
 | 4 | ODOM発注済み品と手持ちMCU・GHコネクタは発注対象外

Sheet: 統合発注BOM
今回発注BOM — 駆動モジュール基板4枚
今回の購入数量は駆動基板4枚分のみ。ODOMは発注済み。価格は税抜JPY。URLは価格/在庫の再確認用。
分類 | 品名/仕様 | メーカー | メーカー品番 | DigiKey品番 | 駆動/枚 | ODOM/枚(発注済) | 今回必要数 | 今回発注数 | 駆動分余剰 | 単価(税抜) | 小計(税抜) | 在庫状態 | 数量判断 | 使用箇所 | 参照URL | 備考
コンデンサ | 100nF 50V X7R 0603 | KEMET | C0603C104K5RACTU | 399-C0603C104K5RACTUCT-ND | 13 | 12 | 52 | 60 | 8 | ¥7.96 | ¥477.60 | 在庫あり | 必要52個＋予備8個。50個価格を適用 | UNIT:C1,C2,C5-C9,C13,C15,C17,C18,C201,C203 / ODOM:C2,C4,C8,C9,C11-C14,C18,C19,C22,C28 | https://www.digikey.jp/ja/products/detail/kemet/C0603C104K5RACTU/1465594
コンデンサ | 10pF 50V C0G 0603 | Samsung Electro-Mechanics | CL10C100JB8NNNC | 1276-1027-1-ND | 2 | 2 | 8 | 10 | 2 | ¥6.20 | ¥62.00 | 在庫あり | 必要8個＋予備2個。10個価格を適用 | UNIT:C3,C4 / ODOM:C6,C7 | https://www.digikey.jp/ja/products/detail/samsung-electro-mechanics/CL10C100JB8NNNC/3886685
コンデンサ | 4.7uF 25V X7R 0805 | Murata | GRM21BZ71E475KE15K | 490-GRM21BZ71E475KE15KCT-ND | 1 | 1 | 4 | 5 | 1 | ¥48.00 | ¥240.00 | 在庫あり | 必要4個＋予備1個。10個購入より総額が低い | UNIT:C10 / ODOM:C10 | https://www.digikey.jp/ja/products/detail/murata-electronics/GRM21BZ71E475KE15K/17860893
コンデンサ | 1uF 25V X7R 0603 | TDK | C1608X7R1E105K080AB | 445-5956-1-ND | 2 | 1 | 8 | 10 | 2 | ¥17.80 | ¥178.00 | 在庫あり | 必要8個＋予備2個。10個価格を適用 | UNIT:C11,C14 / ODOM:C16 | https://www.digikey.jp/ja/products/detail/tdk/C1608X7R1E105K080AB/2443997 | Taiyo Yuden TMK107B7105KA-T在庫0のため同一定格・同外形へ置換
コンデンサ | 10nF 50V C0G 0603 | TDK | C1608C0G1H103J080AA | 445-7404-1-ND | 1 | 0 | 4 | 10 | 6 | ¥22.30 | ¥223.00 | 在庫あり | 必要4個。少数購入より10個の総額が安い | UNIT:C12 | https://www.digikey.jp/ja/products/detail/tdk-corporation/C1608C0G1H103J080AA/2732839 | C0G、±5%、50V、0603を維持し、在庫と価格を確認できる品へ置換
コンデンサ | 10nF 100V X7R 0603 | Murata | GRM188R72A103KA01D | 490-GRM188R72A103KA01DCT-ND | 1 | 0 | 4 | 10 | 6 | ¥5.80 | ¥58.00 | 在庫あり | 必要4個。少数購入より10個の総額が安い | UNIT:C16 | https://www.digikey.jp/ja/products/detail/murata-electronics/GRM188R72A103KA01D/3845635
コンデンサ | 2.2uF 25V X7R 0805 | Murata | GCM21BR71E225KA73L | 490-4787-1-ND | 1 | 4 | 4 | 5 | 1 | ¥73.00 | ¥365.00 | 在庫あり | 必要4個＋予備1個。10個購入より総額が低い | UNIT:C101 / ODOM:C1,C20,C21,C27 | https://www.digikey.jp/ja/products/detail/murata-electronics/GCM21BR71E225KA73L/1641661
コンデンサ | 10uF 10V X7R 0805 | TDK | C2012X7R1A106K125AC | 445-6857-1-ND | 2 | 2 | 8 | 10 | 2 | ¥32.30 | ¥323.00 | 在庫あり | 必要8個＋予備2個。10個価格を適用 | UNIT:C202,C204 / ODOM:C3,C5 | https://www.digikey.jp/ja/products/detail/tdk/C2012X7R1A106K125AC/2619198
抵抗 | 120R 1% 0603 | YAGEO | RC0603FR-07120RL | 311-120HRCT-ND | 1 | 1 | 4 | 10 | 6 | ¥4.20 | ¥42.00 | 在庫あり | 必要4個。少数購入より10個の総額が安い | UNIT:R1 / ODOM:R1 | https://www.digikey.jp/ja/products/detail/yageo/RC0603FR-07120RL/726920
抵抗 | 0R 0603 | YAGEO | RC0603JR-070RL | 311-0.0GRCT-ND | 6 | 1 | 24 | 25 | 1 | ¥1.48 | ¥37.00 | 在庫あり | 必要24個＋予備1個。25個価格を適用 | UNIT:R2,R3,R15-R18 / ODOM:R3 | https://www.digikey.jp/ja/products/detail/yageo/RC0603JR-070RL/726675
抵抗 | 10k 1% 0603 | YAGEO | RC0603FR-0710KL | 311-10.0KHRCT-ND | 1 | 1 | 4 | 10 | 6 | ¥4.20 | ¥42.00 | 在庫あり | 必要4個。少数購入より10個の総額が安い | UNIT:R4 / ODOM:R4 | https://www.digikey.jp/ja/products/detail/yageo/RC0603FR-0710KL/726880
抵抗 | 33k 1% 0603 | YAGEO | RC0603FR-0733KL | 311-33.0KHRCT-ND | 1 | 0 | 4 | 10 | 6 | ¥4.20 | ¥42.00 | 在庫あり | 必要4個。少数購入より10個の総額が安い | UNIT:R13 | https://www.digikey.jp/ja/products/detail/yageo/RC0603FR-0733KL/730106
抵抗 | 22k 1% 0603 | YAGEO | RC0603FR-0722KL | 311-22.0KHRCT-ND | 1 | 0 | 4 | 10 | 6 | ¥4.20 | ¥42.00 | 在庫あり | 必要4個。少数購入より10個の総額が安い | UNIT:R14 | https://www.digikey.jp/ja/products/detail/yageo/RC0603FR-0722KL/727056
抵抗 | 1k 1% 0603 | YAGEO | RC0603FR-071KL | 311-1.00KHRCT-ND | 4 | 4 | 16 | 25 | 9 | ¥3.12 | ¥78.00 | 在庫あり | 必要16個＋予備9個。20個購入より25個の総額が安い | UNIT:R19-R22 / ODOM:R19-R22 | https://www.digikey.jp/ja/products/detail/yageo/RC0603FR-071KL/729790
抵抗 | 100R 1% 0603 | YAGEO | RC0603FR-07100RL | 311-100HRCT-ND | 0 | 6 | 0 | 0 | 0 | ¥0.00 | ¥0.00 | ODOM発注済み | ODOM用は発注済みのため今回購入なし | ODOM:R2,R5-R9 | https://www.digikey.jp/ja/products/detail/yageo/RC0603FR-07100RL/726888
フィルタ | フェライト 600R@100MHz 0603 | Murata | BLM18AG601SN1D | 490-1014-1-ND | 1 | 1 | 4 | 5 | 1 | ¥17.00 | ¥85.00 | 在庫あり | 必要4個＋予備1個。10個購入より総額が低い | UNIT:FB1 / ODOM:FB1 | https://www.digikey.jp/ja/products/detail/murata-electronics/BLM18AG601SN1D/584225
保護 | CAN ESD SOT-23 | Texas Instruments | ESD2CAN24DBZRQ1 | 296-ESD2CAN24DBZRQ1CT-ND | 2 | 1 | 8 | 10 | 2 | ¥89.50 | ¥895.00 | 在庫あり | 必要8個＋予備2個。10個価格を適用 | UNIT:D1,D2 / ODOM:D1 | https://www.digikey.jp/ja/products/detail/texas-instruments/ESD2CAN24DBZRQ1/16982262
保護 | 2ch ESD 5.5V SOT-23 | Texas Instruments | ESDS452DBZR | 296-ESDS452DBZRCT-ND | 0 | 3 | 0 | 0 | 0 | ¥0.00 | ¥0.00 | ODOM発注済み | ODOM用は発注済みのため今回購入なし | ODOM:D2-D4 | https://www.digikey.jp/ja/products/detail/texas-instruments/ESDS452DBZR/23065579 | 2ch双方向、5.5V standoff、3pF
LED | 緑 LED 0603 | Lite-On | LTST-C190KGKT | 160-1435-1-ND | 2 | 2 | 8 | 10 | 2 | ¥17.50 | ¥175.00 | 在庫あり | 必要8個＋予備2個。10個価格を適用 | UNIT:D6,D8 / ODOM:D6,D8 | https://www.digikey.jp/ja/products/detail/liteon/LTST-C190KGKT/386815
ダイオード | BAT54S-HF dual Schottky | Comchip Technology | BAT54S-HF | 641-BAT54S-HFCT-ND | 1 | 0 | 4 | 10 | 6 | ¥21.10 | ¥211.00 | 在庫あり | 必要4個。6個購入との差額1円なので10個 | UNIT:D7 | https://www.digikey.jp/ja/products/detail/comchip-technology/BAT54S-HF/10443826 | onsemi BAT54SLT1GとDiotec BAT54Sが欠品のため、高在庫の同構成・同外形品へ置換
LED | 黄 LED 0603 | Lite-On | LTST-C190KSKT | 160-1437-1-ND | 1 | 1 | 4 | 5 | 1 | ¥25.00 | ¥125.00 | 在庫あり | 必要4個＋予備1個 | UNIT:D9 / ODOM:D9 | https://www.digikey.jp/ja/products/detail/liteon/LTST-C190KSKT/386819
LED | 赤 LED 0603 | Lite-On | LTST-C190KRKT | 160-1436-1-ND | 1 | 1 | 4 | 5 | 1 | ¥23.00 | ¥115.00 | 在庫あり | 必要4個＋予備1個 | UNIT:D10 / ODOM:D10 | https://www.digikey.jp/ja/products/detail/liteon/LTST-C190KRKT/386816
コネクタ | JST GH 2極 横向き | JST | SM02B-GHS-TB | 455-1564-1-ND | 1 | 1 | 4 | 0 | 0 | ¥59.00 | ¥0.00 | 手持ち | 購入不要（必要5個） | UNIT:J1 / ODOM:J1 | https://www.digikey.jp/ja/products/detail/jst-sales-america-inc/SM02B-GHS-TB/807832 | 手持ち在庫を使用
コネクタ | JST GH 3極 横向き | JST | SM03B-GHS-TB | 455-SM03B-GHS-TBCT-ND | 4 | 1 | 16 | 20 | 4 | ¥53.20 | ¥1064.00 | 欠品/繰越注文 | 必要16個＋予備4個。10個価格。欠品のため納期確認必須 | UNIT:J2-J5 / ODOM:J2 | https://www.digikey.jp/ja/products/detail/jst-sales-america-inc/SM03B-GHS-TB/807787 | 2026-09-07確認時に在庫0、標準リードタイム16週。完全同一footprintの在庫品なし
コネクタ | JST GH 6極 横向き | JST | SM06B-GHS-TB | 455-1568-1-ND | 1 | 0 | 4 | 0 | 0 | ¥83.00 | ¥0.00 | 手持ち | 購入不要（必要4個） | UNIT:J6 | https://www.digikey.jp/ja/products/detail/jst-sales-america-inc/SM06B-GHS-TB/807790 | 手持ち在庫を使用
コネクタ | JST GH 6極 垂直 | JST | BM06B-GHS-TBT | 455-BM06B-GHS-TBTCT-ND | 1 | 1 | 4 | 0 | 0 | ¥78.00 | ¥0.00 | 手持ち | 購入不要（必要5個） | UNIT:J7 / ODOM:J8 | https://www.digikey.jp/ja/products/detail/jst-sales-america-inc/BM06B-GHS-TBT/807804 | 手持ち在庫を使用
コネクタ | JST XH 4極 垂直 | JST | B4B-XH-AM | 455-B4B-XH-AM-ND | 0 | 3 | 0 | 0 | 0 | ¥0.00 | ¥0.00 | ODOM発注済み | ODOM用は発注済みのため今回購入なし | ODOM:J4-J6 | https://www.digikey.jp/ja/products/detail/jst-sales-america-inc/B4B-XH-AM/1651035
コネクタ | JST XH 8極 垂直 | JST | B8B-XH-AM | 455-2232-ND | 0 | 1 | 0 | 0 | 0 | ¥0.00 | ¥0.00 | ODOM発注済み | ODOM用は発注済みのため今回購入なし | ODOM:J7 | https://www.digikey.jp/ja/products/detail/jst-sales-america-inc/B8B-XH-AM/1651030
スイッチ | SPDT スライドスイッチ | C&K/Littelfuse | JS102011SAQN | 401-1999-1-ND | 1 | 1 | 4 | 5 | 1 | ¥150.00 | ¥750.00 | 在庫あり | 必要4個＋予備1個 | UNIT:SW1 / ODOM:SW1 | https://www.digikey.jp/ja/products/detail/c-k/JS102011SAQN/1640095
スイッチ | 3極 DIPスイッチ SMD | Same Sky | DS04-254-1-03BK-SMT | 2223-DS04-254-1-03BK-SMT-ND | 1 | 1 | 4 | 5 | 1 | ¥204.00 | ¥1020.00 | 在庫あり | 必要4個＋予備1個 | UNIT:SW3 / ODOM:SW3 | https://www.digikey.jp/ja/products/detail/same-sky-formerly-cui-devices/DS04-254-1-03BK-SMT/11310852 | A6S-3104-H在庫0。pad中心列間8.9mm、縦pitch2.54mm、推奨pad 1.1×1.5mmが既存KiCad footprintと一致
電源IC | Ideal diode 1.5A SC-70-6 | Texas Instruments | LM66100DCKT | 296-53540-1-ND | 1 | 1 | 4 | 5 | 1 | ¥160.00 | ¥800.00 | 在庫あり | 必要4個＋予備1個 | UNIT:U1 / ODOM:U5 | https://www.digikey.jp/ja/products/detail/texas-instruments/LM66100DCKT/10273182 | DCKRと同一IC・同一SC-70-6、梱包数量だけ異なる
電源IC | 3.3V LDO SOT-223 | Texas Instruments | TLV76133DCYR | 296-TLV76133DCYRCT-ND | 1 | 1 | 4 | 5 | 1 | ¥98.00 | ¥490.00 | 在庫あり | 必要4個＋予備1個 | UNIT:U2 / ODOM:U2 | https://www.digikey.jp/ja/products/detail/texas-instruments/TLV76133DCYR/18716472 | TLV1117LV33DCYR生産中止のため、同一ピン配置・セラミック安定品へ置換
通信IC | CAN transceiver with VIO | Texas Instruments | TCAN1051VDRQ1 | 296-44228-1-ND | 2 | 1 | 8 | 10 | 2 | ¥318.80 | ¥3188.00 | 在庫あり | 必要8個＋予備2個。10個価格を適用 | UNIT:U3,U5 / ODOM:U4 | https://www.digikey.jp/ja/products/detail/texas-instruments/TCAN1051VDRQ1/6052110
ロジックIC | Dual Schmitt buffer SOT-23-6 | Texas Instruments | SN74LVC2G17DBVT | 296-26621-1-ND | 0 | 3 | 0 | 0 | 0 | ¥0.00 | ¥0.00 | ODOM発注済み | ODOM用は発注済みのため今回購入なし | ODOM:U3,U7,U9 | https://www.digikey.jp/ja/products/detail/texas-instruments/SN74LVC2G17DBVT/2255079 | DBVRと同一IC・同一SOT-23-6、梱包数量だけ異なる
水晶 | 8MHz 8pF 500R 3225-4pad | Fox Electronics | FC3BAEBDI8.0-T1 | 631-FC3BAEBDI8.0-T1CT-ND | 1 | 1 | 4 | 5 | 1 | ¥98.00 | ¥490.00 | 在庫あり | 必要4個＋予備1個 | UNIT:Y1 / ODOM:Y1 | https://www.digikey.jp/ja/products/detail/fox-electronics/FC3BAEBDI8-0-T1/21293019 | ECS元品欠品。8MHz、CL=8pF、ESR=500Ω、3225-4pad一致。AEC-Q200
手持ち | Drive MCU LQFP64 | STMicroelectronics | STM32G474RET6 | 497-STM32G474RET6-ND | 1 | 0 | 4 | 0 | 0 | ¥0.00 | ¥0.00 | 手持ち10個 | 購入不要（4個使用） | UNIT:U4 | https://www.digikey.jp/ja/products/detail/stmicroelectronics/STM32G474RET6/10326780
手持ち | Odometry MCU LQFP64 | STMicroelectronics | STM32F405RGT6 | 497-STM32F405RGT6-ND | 0 | 1 | 0 | 0 | 0 | ¥0.00 | ¥0.00 | ODOM発注済み | ODOM用は発注済みのため今回購入なし | ODOM:U1 | https://www.digikey.jp/ja/products/detail/stmicroelectronics/STM32F405RGT6/1851915
手持ち | IMU 8pin breakout | TDK InvenSense | ICM-42688-P breakout |  | 0 | 1 | 0 | 0 | 0 | ¥0.00 | ¥0.00 | ODOM発注済み | ODOM用は発注済みのため今回購入なし | ODOM:J7接続 |  | 基板実装部品ではない

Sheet: 駆動基板_4枚
駆動モジュール基板 — 4枚分（実機3＋予備1）
分類 | 品名/仕様 | メーカー品番 | 使用箇所 | 1枚あたり | 枚数 | 合計必要数 | 調達区分
コンデンサ | 100nF 50V X7R 0603 | C0603C104K5RACTU | UNIT:C1,C2,C5-C9,C13,C15,C17,C18,C201,C203 | 13 | 4 | 52 | 今回発注
コンデンサ | 10pF 50V C0G 0603 | CL10C100JB8NNNC | UNIT:C3,C4 | 2 | 4 | 8 | 今回発注
コンデンサ | 4.7uF 25V X7R 0805 | GRM21BZ71E475KE15K | UNIT:C10 | 1 | 4 | 4 | 今回発注
コンデンサ | 1uF 25V X7R 0603 | C1608X7R1E105K080AB | UNIT:C11,C14 | 2 | 4 | 8 | 今回発注
コンデンサ | 10nF 50V C0G 0603 | C1608C0G1H103J080AA | UNIT:C12 | 1 | 4 | 4 | 今回発注
コンデンサ | 10nF 100V X7R 0603 | GRM188R72A103KA01D | UNIT:C16 | 1 | 4 | 4 | 今回発注
コンデンサ | 2.2uF 25V X7R 0805 | GCM21BR71E225KA73L | UNIT:C101 | 1 | 4 | 4 | 今回発注
コンデンサ | 10uF 10V X7R 0805 | C2012X7R1A106K125AC | UNIT:C202,C204 | 2 | 4 | 8 | 今回発注
抵抗 | 120R 1% 0603 | RC0603FR-07120RL | UNIT:R1 | 1 | 4 | 4 | 今回発注
抵抗 | 0R 0603 | RC0603JR-070RL | UNIT:R2,R3,R15-R18 | 6 | 4 | 24 | 今回発注
抵抗 | 10k 1% 0603 | RC0603FR-0710KL | UNIT:R4 | 1 | 4 | 4 | 今回発注
抵抗 | 33k 1% 0603 | RC0603FR-0733KL | UNIT:R13 | 1 | 4 | 4 | 今回発注
抵抗 | 22k 1% 0603 | RC0603FR-0722KL | UNIT:R14 | 1 | 4 | 4 | 今回発注
抵抗 | 1k 1% 0603 | RC0603FR-071KL | UNIT:R19-R22 | 4 | 4 | 16 | 今回発注
フィルタ | フェライト 600R@100MHz 0603 | BLM18AG601SN1D | UNIT:FB1 | 1 | 4 | 4 | 今回発注
保護 | CAN ESD SOT-23 | ESD2CAN24DBZRQ1 | UNIT:D1,D2 | 2 | 4 | 8 | 今回発注
LED | 緑 LED 0603 | LTST-C190KGKT | UNIT:D6,D8 | 2 | 4 | 8 | 今回発注
ダイオード | BAT54S-HF dual Schottky | BAT54S-HF | UNIT:D7 | 1 | 4 | 4 | 今回発注
LED | 黄 LED 0603 | LTST-C190KSKT | UNIT:D9 | 1 | 4 | 4 | 今回発注
LED | 赤 LED 0603 | LTST-C190KRKT | UNIT:D10 | 1 | 4 | 4 | 今回発注
コネクタ | JST GH 2極 横向き | SM02B-GHS-TB | UNIT:J1 | 1 | 4 | 4 | 手持ち
コネクタ | JST GH 3極 横向き | SM03B-GHS-TB | UNIT:J2-J5 | 4 | 4 | 16 | 今回発注
コネクタ | JST GH 6極 横向き | SM06B-GHS-TB | UNIT:J6 | 1 | 4 | 4 | 手持ち
コネクタ | JST GH 6極 垂直 | BM06B-GHS-TBT | UNIT:J7 | 1 | 4 | 4 | 手持ち
スイッチ | SPDT スライドスイッチ | JS102011SAQN | UNIT:SW1 | 1 | 4 | 4 | 今回発注
スイッチ | 3極 DIPスイッチ SMD | DS04-254-1-03BK-SMT | UNIT:SW3 | 1 | 4 | 4 | 今回発注
電源IC | Ideal diode 1.5A SC-70-6 | LM66100DCKT | UNIT:U1 | 1 | 4 | 4 | 今回発注
電源IC | 3.3V LDO SOT-223 | TLV76133DCYR | UNIT:U2 | 1 | 4 | 4 | 今回発注
通信IC | CAN transceiver with VIO | TCAN1051VDRQ1 | UNIT:U3,U5 | 2 | 4 | 8 | 今回発注
水晶 | 8MHz 8pF 500R 3225-4pad | FC3BAEBDI8.0-T1 | UNIT:Y1 | 1 | 4 | 4 | 今回発注
手持ち | Drive MCU LQFP64 | STM32G474RET6 | UNIT:U4 | 1 | 4 | 4 | 手持ち

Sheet: ODOM基板_1枚
ODOM基板 — 1枚分（発注済み・組立確認用）
分類 | 品名/仕様 | メーカー品番 | 使用箇所 | 1枚あたり | 枚数 | 合計必要数 | 調達区分
コンデンサ | 100nF 50V X7R 0603 | C0603C104K5RACTU | ODOM:C2,C4,C8,C9,C11-C14,C18,C19,C22,C28 | 12 | 1 | 12 | 発注済み
コンデンサ | 10pF 50V C0G 0603 | CL10C100JB8NNNC | ODOM:C6,C7 | 2 | 1 | 2 | 発注済み
コンデンサ | 4.7uF 25V X7R 0805 | GRM21BZ71E475KE15K | ODOM:C10 | 1 | 1 | 1 | 発注済み
コンデンサ | 1uF 25V X7R 0603 | C1608X7R1E105K080AB | ODOM:C16 | 1 | 1 | 1 | 発注済み
コンデンサ | 2.2uF 25V X7R 0805 | GCM21BR71E225KA73L | ODOM:C1,C20,C21,C27 | 4 | 1 | 4 | 発注済み
コンデンサ | 10uF 10V X7R 0805 | C2012X7R1A106K125AC | ODOM:C3,C5 | 2 | 1 | 2 | 発注済み
抵抗 | 120R 1% 0603 | RC0603FR-07120RL | ODOM:R1 | 1 | 1 | 1 | 発注済み
抵抗 | 0R 0603 | RC0603JR-070RL | ODOM:R3 | 1 | 1 | 1 | 発注済み
抵抗 | 10k 1% 0603 | RC0603FR-0710KL | ODOM:R4 | 1 | 1 | 1 | 発注済み
抵抗 | 1k 1% 0603 | RC0603FR-071KL | ODOM:R19-R22 | 4 | 1 | 4 | 発注済み
抵抗 | 100R 1% 0603 | RC0603FR-07100RL | ODOM:R2,R5-R9 | 6 | 1 | 6 | 発注済み
フィルタ | フェライト 600R@100MHz 0603 | BLM18AG601SN1D | ODOM:FB1 | 1 | 1 | 1 | 発注済み
保護 | CAN ESD SOT-23 | ESD2CAN24DBZRQ1 | ODOM:D1 | 1 | 1 | 1 | 発注済み
保護 | 2ch ESD 5.5V SOT-23 | ESDS452DBZR | ODOM:D2-D4 | 3 | 1 | 3 | 発注済み
LED | 緑 LED 0603 | LTST-C190KGKT | ODOM:D6,D8 | 2 | 1 | 2 | 発注済み
LED | 黄 LED 0603 | LTST-C190KSKT | ODOM:D9 | 1 | 1 | 1 | 発注済み
LED | 赤 LED 0603 | LTST-C190KRKT | ODOM:D10 | 1 | 1 | 1 | 発注済み
コネクタ | JST GH 2極 横向き | SM02B-GHS-TB | ODOM:J1 | 1 | 1 | 1 | 発注済み
コネクタ | JST GH 3極 横向き | SM03B-GHS-TB | ODOM:J2 | 1 | 1 | 1 | 発注済み
コネクタ | JST GH 6極 垂直 | BM06B-GHS-TBT | ODOM:J8 | 1 | 1 | 1 | 発注済み
コネクタ | JST XH 4極 垂直 | B4B-XH-AM | ODOM:J4-J6 | 3 | 1 | 3 | 発注済み
コネクタ | JST XH 8極 垂直 | B8B-XH-AM | ODOM:J7 | 1 | 1 | 1 | 発注済み
スイッチ | SPDT スライドスイッチ | JS102011SAQN | ODOM:SW1 | 1 | 1 | 1 | 発注済み
スイッチ | 3極 DIPスイッチ SMD | DS04-254-1-03BK-SMT | ODOM:SW3 | 1 | 1 | 1 | 発注済み
電源IC | Ideal diode 1.5A SC-70-6 | LM66100DCKT | ODOM:U5 | 1 | 1 | 1 | 発注済み
電源IC | 3.3V LDO SOT-223 | TLV76133DCYR | ODOM:U2 | 1 | 1 | 1 | 発注済み
通信IC | CAN transceiver with VIO | TCAN1051VDRQ1 | ODOM:U4 | 1 | 1 | 1 | 発注済み
ロジックIC | Dual Schmitt buffer SOT-23-6 | SN74LVC2G17DBVT | ODOM:U3,U7,U9 | 3 | 1 | 3 | 発注済み
水晶 | 8MHz 8pF 500R 3225-4pad | FC3BAEBDI8.0-T1 | ODOM:Y1 | 1 | 1 | 1 | 発注済み
手持ち | Odometry MCU LQFP64 | STM32F405RGT6 | ODOM:U1 | 1 | 1 | 1 | 発注済み
手持ち | IMU 8pin breakout | ICM-42688-P breakout | ODOM:J7接続 | 1 | 1 | 1 | 発注済み

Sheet: 判断根拠と注意
数量判断・置換・組立時の注意
項目 | 判断 | 理由 | 次の確認
基板枚数 | 今回発注は駆動4枚のみ | 駆動は3ユニット実装＋基板単位の完全予備1枚。ODOMは発注済み | 枚数を変える場合は今回発注BOMのF列と発注数を再調整
受動部品 | 必要数＋2〜6個、安価品は価格境界まで | 紛失・はんだ不良・再作業を吸収 | 0603は向き/定数を仕分けしてから実装
高価なIC/スイッチ | 基本は必要数＋1個 | 死蔵を避けながら初期不良と実装ミスを1回吸収 | 開封時にロットと向きを確認
LM66100DCKT | 採用 | DCKRとDCKTは同じLM66100・SC-70-6で梱包数量だけ違う | DigiKeyカットテープ品番を使用
SN74LVC2G17DBVT | 採用 | DBVRとDBVTは同じTI品・SOT-23-6で梱包数量だけ違う | 1番ピンを確認
FC3BAEBDI8.0-T1 | 採用 | 元ECS品欠品。8MHz、CL=8pF、ESR=500R、3225 4padが一致 | 初号機で発振開始と周波数を確認
BAT54S-HF (Comchip) | 採用 | onsemi/Diotec品欠品。直列2ダイオード、30V、200mA、SOT-23、同一ピン構成 | 初号機でD7向きとクランプ動作を確認
TLV76133DCYR | 採用 | TLV1117LV33DCYR生産中止。SOT-223同一ピン配置、1A、セラミック出力コンデンサ対応 | 初号機で3.3V、温度、負荷変動を確認
DS04-254-1-03BK-SMT | 採用 | A6S-3104-H在庫0。推奨ランドの列間8.9mm・縦pitch 2.54mm・pad 1.5x1.1mmが既存KiCad footprintと一致 | シルクはA6S名称のままだが実装ランドは一致。ON方向を実装前に確認
SM03B-GHS-TB | 繰越注文 | 確認時DigiKey在庫0。形状違いの代替は基板に合わないため未採用 | 発注前にカート納期確認。急ぐ場合は別在庫元を探す
ODOM DNP | C15,C17,C23-C26は購入・実装しない | KiCad回路図でDNP指定 | 組立指示にもDNPを残す
発注対象外 | ODOM一式、STM32G474RET6×4、GH 2極横/6極横/6極垂直（必要数を満たす前提） | 発注済み/手持ちのためCSVから除外 | 駆動用GHは必要数4/4/4個を満たすか現物確認
価格 | DigiKey Japan税抜JPY、2026-09-07時点 | 価格と在庫は変動する | カート取込後に最終総額を再確認
BOM範囲 | 基板実装部品のみ | GH/XH相手側ハウジング・圧着端子・ケーブル、PCB、ステンシル、はんだ材料は含めない | ハーネス長と本数の確定後に別BOM化
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

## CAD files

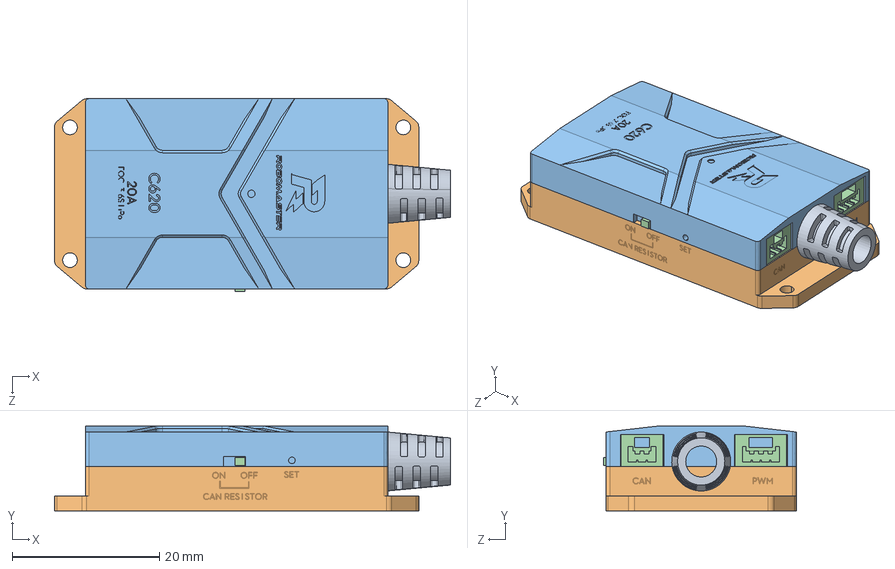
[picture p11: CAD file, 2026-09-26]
cad/current/load tester ver2/c620.SLDASM
53.7 x 11.5 x 26.1 mm

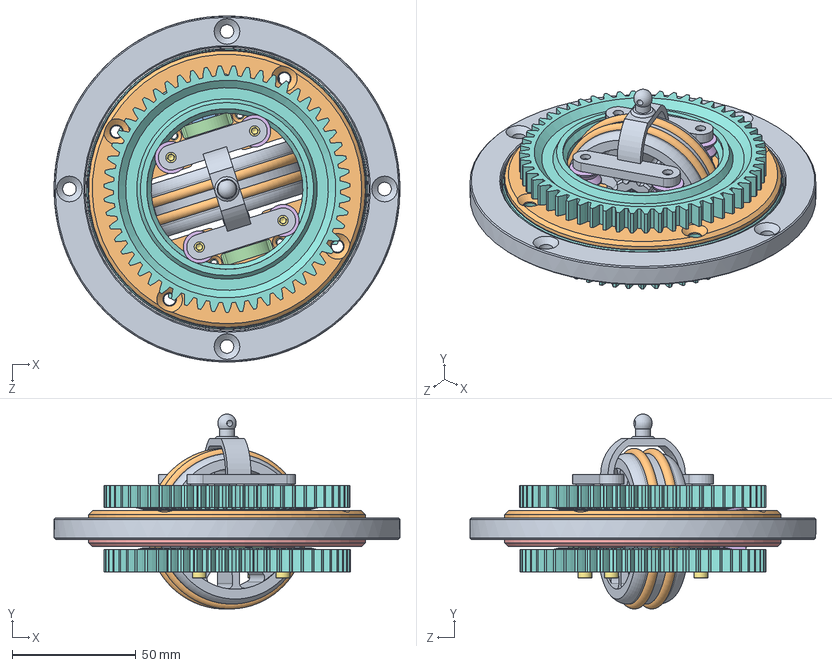
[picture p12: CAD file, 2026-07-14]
cad/current/ver5/differencial drive unit/differencial drive_ver4/Users/posak/Desktop/趣味/Differential-Swerve-Drive/cad/current/ver5/differencial drive unit/drive unit ver4.SLDASM
139.9 x 78.9 x 140.0 mm
main wheel^wheel
friction ring^wheel x 2
hexagon nut style 1_ab_jis x 4
Copy of Part3^wheel
spring pin_ab_jis
15T straight bevel pinion2
m6 bolt
inner ring^turntable
outor ring^turntable
Part1^wheel mount_drive unit ver4
bearing x 2
Part2^Assem2_wheel mount_drive unit ver4 x 2
Copy of Part1^wheel mount_drive unit ver4
v-groove bearing x 8
hexagon socket head cap screw_jis x 8
gear ver2 x 2
Part4^drive unit ver4

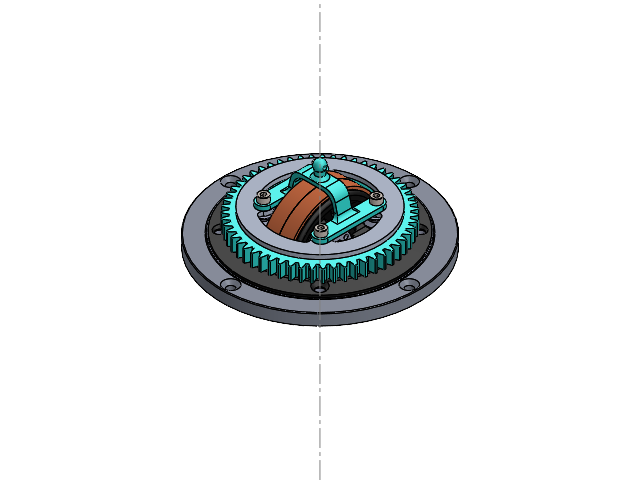
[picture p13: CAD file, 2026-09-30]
cad/current/ver5/differencial drive unit ver8/Drive unit ver 8.SLDASM
gear ver5 x 2
inner ring
outor ring^turntable ver2
v-groove bearing ver2 x 8
M6 Flanzi x 2
wheel x 2
80XL belt x 2
bearing x 2
m6 bolt
hexagon nut style 1_ab_jis x 2
bevel gear(15T 2)
Spacer
Spacer2
Top plate
Bottom plate
gear cover
gear cover (bottom)
hexagon socket head cap screw_jis x 4
encorder joint

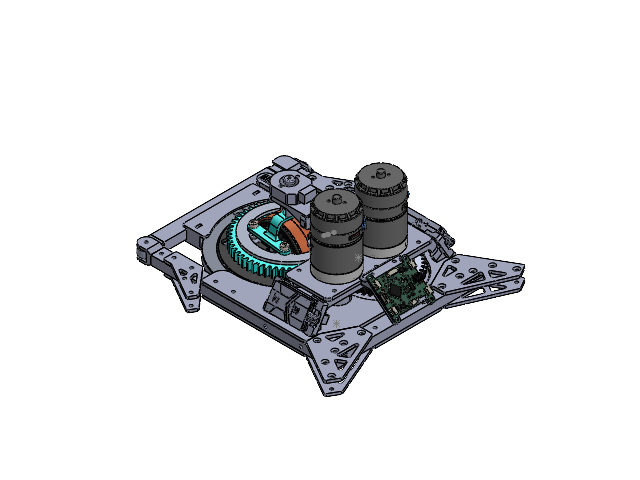
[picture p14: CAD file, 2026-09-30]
cad/current/ver5/differencial drive unit/differencial drive.SLDASM
Anguler pipe 10×15 205.5mm
Anguler pipe 10×15 205.5mm
角パイ 2
Top plate_1
Top plate_2
bottom palte_1 x 2
main bodey
top plate_5
Copy of Part7^motor plate
Part2^motor plate x 2
40T module1.75
Part1^top motor drive
Copy of Part1^top motor drive
40T module1.75(bottom)
Flanzi
Rigid coupling
top plate_4
AMT102V
Encorder coupling
Encorder bearing
Coupling end
HG_TS03_body_A
HG_TS03_body_B
Part1^quick-release unit
Part2^quick-release unit
Part3^quick-release unit
Copy of Part3^quick-release unit
Part4^quick-release unit
Copy of Part4^quick-release unit
C-1075___o_[_x_[_X_.STEP
C-1075_t_b_N_x_[_X_.STEP
C-1075_t_b_N_.STEP
C-1075___o_[_.STEP
C-1075___o_[_J_V_____.STEP
Copy of Part7^c620 x 4
end cap(10×15) x 2
unit_board
Board backle
gear ver5 x 2
inner ring
outor ring^turntable ver2
v-groove bearing ver2 x 8
M6 Flanzi x 2
wheel x 2
80XL belt x 2
bearing x 2
m6 bolt
hexagon nut style 1_ab_jis x 2
bevel gear(15T 2)
Spacer
Spacer2
Top plate
Bottom plate
gear cover
gear cover (bottom)
hexagon socket head cap screw_jis x 4
encorder joint
Encorder bracket
top plate_3 x 2

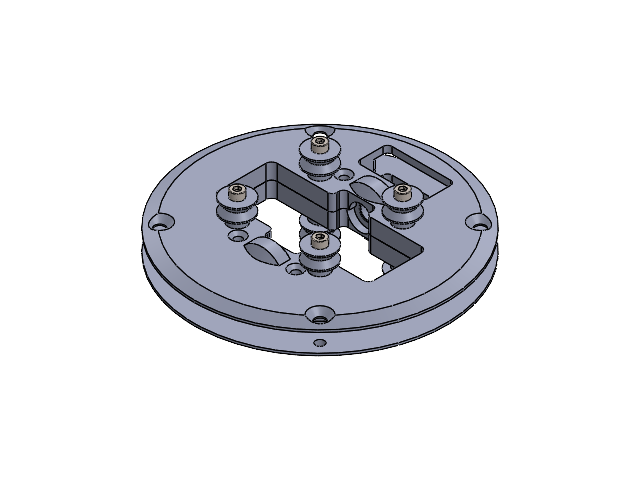
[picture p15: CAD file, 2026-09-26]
cad/current/ver5/differencial drive unit/differencial drive_ver4/wheel mount.SLDASM
bearing x 2
v-groove bearing x 8
hexagon socket head cap screw_jis x 8
top wheel assy
bottom assy

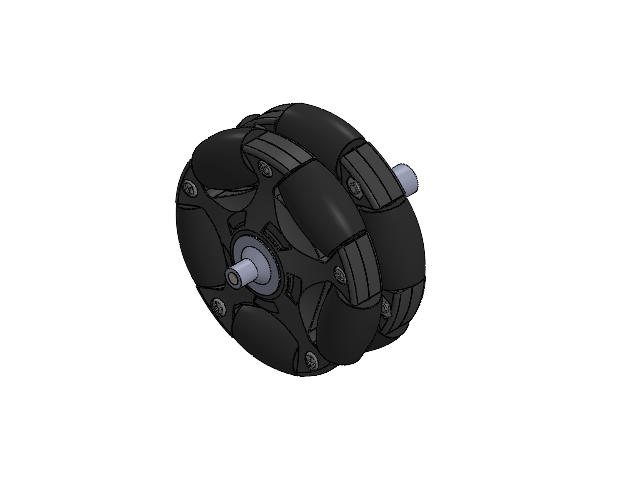
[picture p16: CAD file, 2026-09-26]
cad/current/ver5/oddom unit/oddom wheel assem.SLDASM
58mm omni wheel
wheel hub_1
wheel hun_2
50mm m3
Part1^oddom wheel assem

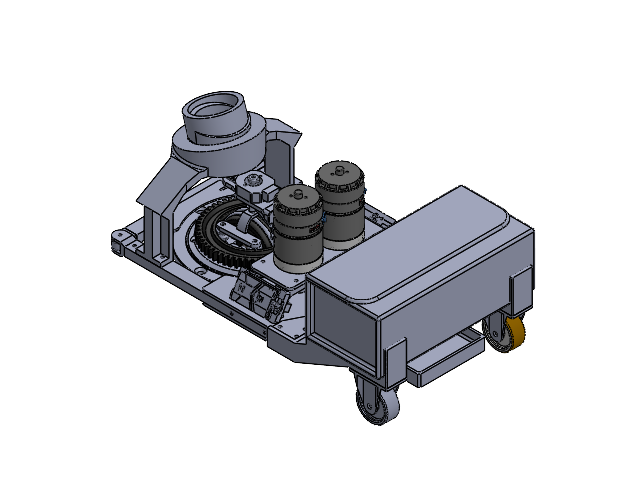
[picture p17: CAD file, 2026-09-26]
cad/current/load tester/drive module.SLDASM
Anguler pipe 10×15 205.5mm
Anguler pipe 10×15 205.5mm
Anguler pipe 10×15 141mm
main wheel
friction ring x 2
hexagon nut style 1_ab_jis x 4
Copy of Part3
spring pin_ab_jis
15T straight bevel pinion2
m6 bolt
Copy of Copy of Part3
inner ring^turntable
outor ring^turntable
bearing x 2
v-groove bearing x 8
hexagon socket head cap screw_jis x 8
top wheel assy
bottom assy
gear ver2 x 2
encorder joint
main bodey
Copy of Part7^motor plate
Part2^motor plate x 2
40T module1.75
Part1^top motor drive
Copy of Part1^top motor drive
40T module1.75(bottom)
Part2^bottom motor drive
Part3^bottom motor drive
Part6^encorder unit
HG_TS03_body_A
HG_TS03_body_B
Part1^quick-release unit
Part2^quick-release unit
Part3^quick-release unit
Copy of Part3^quick-release unit
Part4^quick-release unit
Copy of Part4^quick-release unit
C-1075___o_[_x_[_X_.STEP
C-1075_t_b_N_x_[_X_.STEP
C-1075_t_b_N_.STEP
C-1075___o_[_J_V_____.STEP
Copy of Part7^c620 x 4
end cap(10×15) x 2
38mm wheel
wheel housing
lipo
Part2^drive module
Part3^drive module
ﾐﾗｰCopy of Part1
ﾐﾗｰPart2
ﾐﾗｰPart3

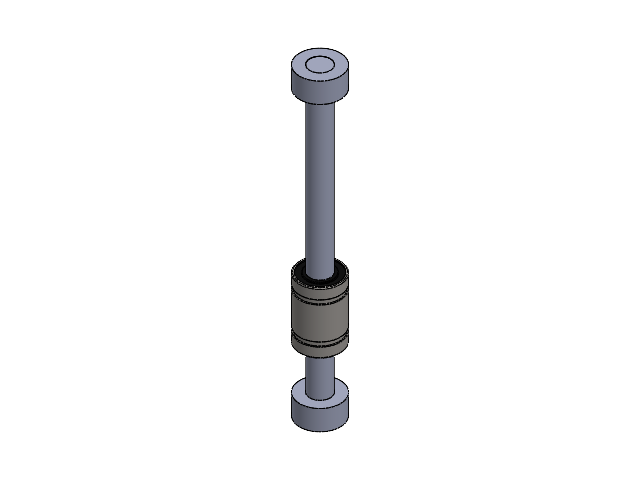
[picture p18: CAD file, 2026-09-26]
cad/current/ver5/oddom unit/suspension.SLDASM
75mm linear shaft
5mm collar x 2
LM5UU

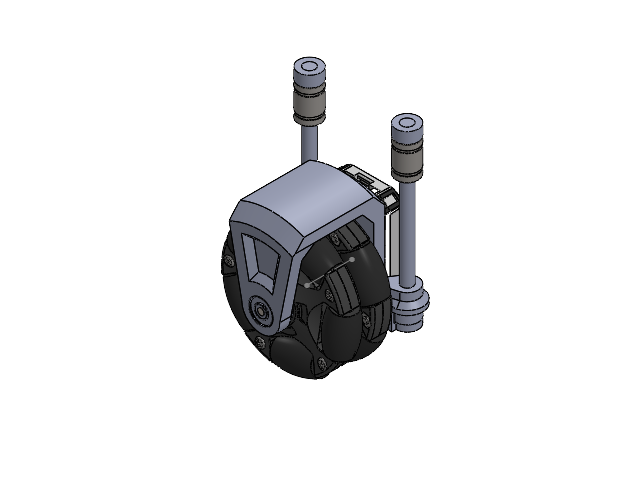
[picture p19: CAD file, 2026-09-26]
cad/current/ver5/oddom unit/oddom unit.SLDASM
amt102-v_01
amt102-v_02
amt102-v_04
amt102-v_05
amt102-v_06
F685ZZ x 2
75mm linear shaft x 2
5mm collar x 4
LM5UU x 2
58mm omni wheel
wheel hub_1
wheel hun_2
50mm m3
Part1^oddom wheel assem
Part9^oddom unit
Part10^oddom unit

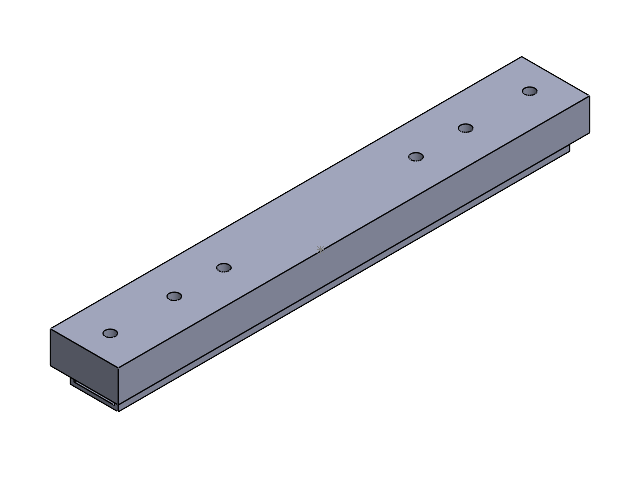
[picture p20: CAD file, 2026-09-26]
cad/current/Jig/穴あけガイド4.SLDASM
角パイ 2

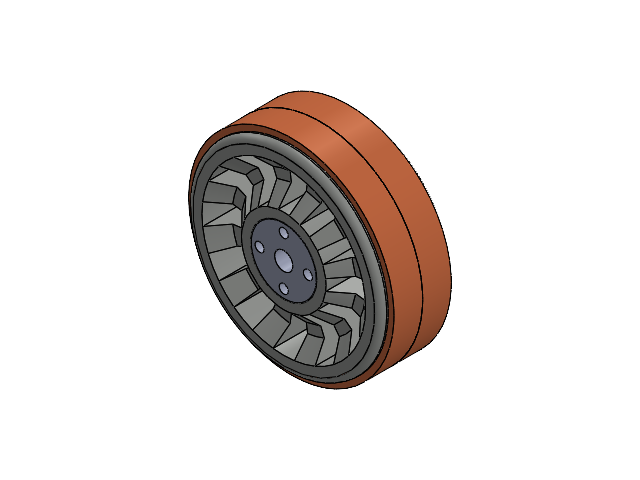
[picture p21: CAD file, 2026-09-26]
cad/current/load tester ver2/wheel.SLDASM
M6 Flanzi x 2
wheel x 2
80XL belt x 2

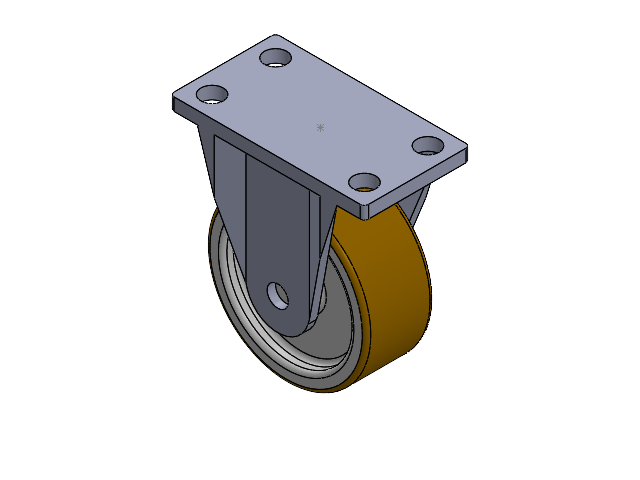
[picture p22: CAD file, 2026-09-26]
cad/current/load tester/38mm wheel.SLDASM
38mm wheel
wheel housing

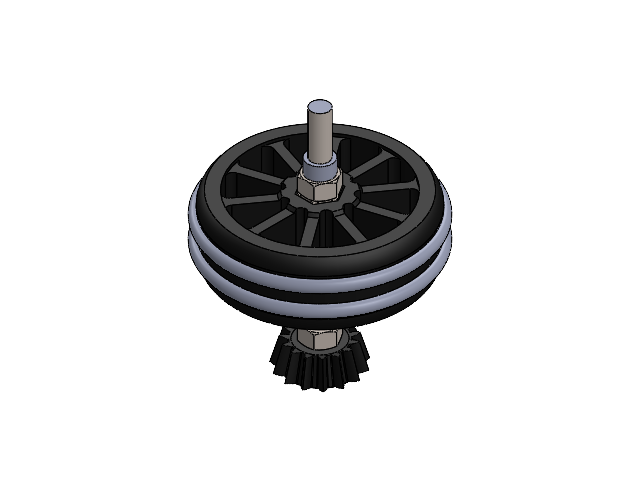
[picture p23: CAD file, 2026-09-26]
cad/current/ver5/differencial drive unit/wheel.SLDASM
main wheel
friction ring x 2
hexagon nut style 1_ab_jis x 4
Copy of Part3
spring pin_ab_jis
15T straight bevel pinion2
m6 bolt
Copy of Copy of Part3

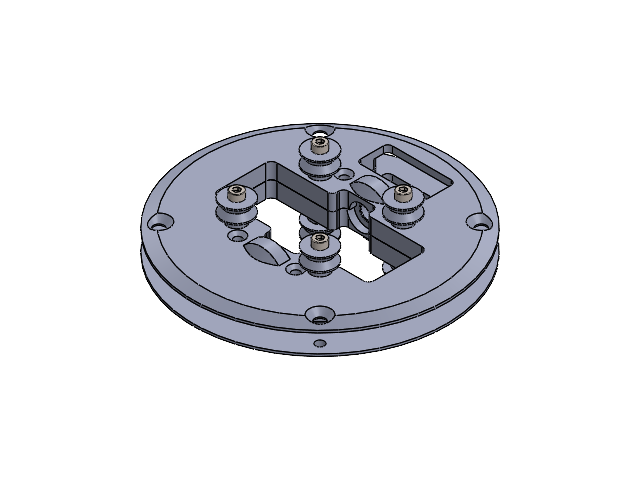
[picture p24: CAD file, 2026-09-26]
cad/current/ver5/differencial drive unit ver8/wheel mount.SLDASM
bearing x 2
v-groove bearing x 8
hexagon socket head cap screw_jis x 8
top wheel assy
bottom assy

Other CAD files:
cad/current/load tester/ﾐﾗｰ38mm wheel.SLDASM
cad/current/ver5/LQFP-64_10x10mm_P0.5mm.step.SLDASM
cad/current/ver5/differencial drive unit/2_ASM.SLDASM
cad/current/ver5/SOT-363_SC-70-6.step.SLDASM
CNC/Copy of Part7^motor plate.STEP
CNC/Top plate_2.STEP
CNC/bottom palte_1.STEP
CNC/gear cover (bottom).STEP
CNC/gear cover.STEP
CNC/top plate_4.STEP
CNC/top plate_5.STEP
cad/current/Jig/10×15 角パイプ穴あけガイド.SLDASM
cad/current/Jig/139mm (oddom).SLDPRT
cad/current/Jig/430mm (oddom).SLDPRT
cad/current/Jig/Anguler pipe 10×15 141mm.SLDPRT
cad/current/Jig/Anguler pipe 10×15 205.5mm (lock side).SLDPRT
cad/current/Jig/Anguler pipe 10×15 205.5mm.SLDPRT
cad/current/Jig/Assem1.SLDASM
cad/current/Jig/Assem2.SLDASM
cad/current/Jig/M6穴あけ.SLDASM
cad/current/Jig/Part2.SLDPRT
cad/current/Jig/Part2^Assem1_Assem2_Assem1_differential drive unit.SLDPRT
cad/current/Jig/Part3.SLDPRT
cad/current/Jig/Part4.SLDPRT
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

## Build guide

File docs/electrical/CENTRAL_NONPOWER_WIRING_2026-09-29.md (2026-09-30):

> **作業先訂正 2026-09-29:** 現行は `hardware/central-board/central-board/central-board.kicad_pro`。22:45保存版へ移行済みで、クランプD405も `safety-1.kicad_sch` に反映済み。ERC0件。下記のcentral-board-placement対象/既存CAN4件という記載は以前の作業履歴。

> **2026-09-29採用更新:** ユーザー承認によりX401を **D405: Alpha & Omega Semiconductor SMBJ33CA（双方向TVS）**へ置換。J402-1（ESTOP_LOOP_RETURN/COIL_POS）とJ402-2（COIL_NEG）の間へ並列。symbol=`Device:D_TVS`、footprint=`Diode_SMD:D_SMB`。型番選定・KiCad反映済み、実ハーネスでのサージ/吸収エネルギー/解放10ms以内は実測残件。X402帰路結合は未確定。

# 中央基板：電源・CAN以外のKiCad配線

2026-09-29。対象は `hardware/central-board-placement/central-board-placement.kicad_pro`。ユーザーの「電源can以外全部…kicadの回路作成」の指定に基づく。旧 `hardware/central-board/central-board/` は今回の編集対象ではない。

## 反映内容

- S02B：Teensyの既存用途global label（使用40端子・予約NC8端子）とREARM RC回路を維持。D212赤をSTATUS_R_LED/R212へ、D213緑を+5V_SYS/R213へ訂正。D211緑はSTATUS_G_LED/R211。
- S04：J403の24V入力、F401、J401のNCループ往復、J402のコイル、U401 LTV-817S監視、R401/R402/D401、R409、TP401/TP406、U402/Q401の駆動・プルダウン・デカップリングを接続。保存版で消えていたJ401を現行4pin仕様で復元。
- S05：I2C0/1、UART7/8、SPI、GPIO8信号の100Ω直列抵抗とSRV05-4を配線。I2Cの2.2kΩプルアップはJP501〜504を介し、初期OPEN。GPIOをJ507〜J510の4pin×4組へ変更。JP505は4ポート共通の電源選択（初期1-2＝3.3V）。5V選択でも信号は3.3V固定。
- 目次の「未配線」表示を修正し、parts JSON/manifestを現保存版157参照番号へ同期。製造用BOMとしての確定ではない。
- S02A、S03_CAN1/2/3の回路図ファイルは編集前とバイト一致。電源/CAN内のネット構成も保存されている。PCB・ファームは変更していない。

## S04のコネクタと未確定インターフェース

| 端子 | 接続 |
|---|---|
| J403-1 / 2 | +24V_CTRL_IN / GND_24V_RETURN |
| J401-1 | ESTOP_LOOP_OUT（F401後、外部NC1→NC2へ） |
| J401-2 | ESTOP_LOOP_RETURN（外部NC直列の戻り、J402-1と監視抵抗へ） |
| J401-3 / 4 | ESTOP_LED_24V（F402後）/ GND_CTRL_LED |
| J402-1 / 2 | ESTOP_LOOP_RETURN（COIL_POS）/ COIL_NEG |
| X401-1 / 2 | コイル両端。クランプ方式・型番・解放時間未確定の機能ブロック |
| X402-1 / 2 / 3 | GND_CTRL / GND_CTRL_LED / GND_24V_RETURN |

**X402は導通を持つnet tieではない。** 帰路の結合位置・配線方針を未確定のまま見える形にしたインターフェースで、3本のネットを自動的に短絡していない。ドライバを動かすには論理GNDとコイル帰路の基準を確定する必要がある。X401も採用部品ではない。いずれもfootprintなしのTBD。

F401の定格、追加したF402（LED枝保護）の方式/定格、X401、X402、J401/J402/J403の正式品、SW211等の既存未確定品は残る。24V LED約0.3Wのユーザー実測を保持し、測定個数・接点動作・LED極性の未確認を確定扱いにしない。回路図上の配線完了と、実機使用・製造可能な設計の完了は別。

## GPIO4ポート

| コネクタ | 1 | 2 | 3 | 4 |
|---|---|---|---|---|
| J507 | VCC_GPIO_EXT | GND_CTRL | IO20_A6_EXT | IO21_A7_EXT |
| J508 | VCC_GPIO_EXT | GND_CTRL | IO24_A10_EXT | IO25_A11_EXT |
| J509 | VCC_GPIO_EXT | GND_CTRL | IO26_A12_EXT | IO27_A13_EXT |
| J510 | VCC_GPIO_EXT | GND_CTRL | IO40_A16_EXT | IO41_A17_EXT |

既存J502/J503と共通のSM04B-GHS-TB、KiCad標準 `JST_GH_SM04B-GHS-TB_1x04-1MP_P1.25mm_Horizontal` を使用。[JST公式GH資料](https://www.jst-mfg.com/product/pdf/eng/eGH.pdf)の4極型番、端子番号方向、1.25mmピッチ、基板パターンを確認。GHの50V/1A（AWG26）定格はシリーズ値で、回路側の枝制限や外部3.3V合計100mAの予算を増やすものではない。24V側J401等への自動流用はしていない。

## 確認結果と限界

- KiCad 10 CLI exportで指定186端子を照合。別途Teensy全48pad、GPIO4組、LED色と接続、フォトカプラ/逆並列ダイオード、MOSFET G/S/D、JP505、電源ネットの意図しない合流なしを検査。
- 電源/CANの4ファイルのSHA-256一致と、これらの既存部品間接続の一致を検査。
- ERCは編集前193件（error167/warning26）→編集後4件（error4/warning0）。残りは対象外CANのU311 VCC/VIO、U312 VIO、U313 VIOの `power_pin_not_driven`。今回のS02B/S04/S05は既存プロジェクト設定で0件。
- ERC設定・除外設定は変更していない。既存設定ではglobal label片端等4種類が無効のため、ERCだけに依存せずnetlistを照合した。TBD機能ブロックはERCだけでは未完成を検出できない。
- 3シートのSVGを書き出し、全体画像と安全回路拡大で表示を確認。1.27mm接続グリッドへ整列。古いPDFは説明用の前回版であり、今回のKiCad完全一致版ではない。

検証記録・編集前退避：`output/kicad-check/central-nonpower-wiring-2026-09-29/`。検証スクリプト：`tools/kicad/audit-central-nonpower-2026-09-29.py`。作成/整列/同期スクリプトはこの保存版向けの一回限りの移行用で、通常編集後に再実行しない。

次はS04の保護・帰路・コネクタを確定し、対象外CANの電源ERCを別途解消する。KiCadを開いたままの場合は、古い画面を保存せず外部変更を再読込する。

## 追記：TN686実測とX401試作候補（2026-09-29）

現物はユーザー申告TN686・24V/100A、コイル340Ω、内部保護なし。24V時約70.6mA/1.69W。解放10ms未満は掲載仕様で、外付けクランプを含む実測値ではない。

試作候補は **Littelfuse SMBJ33CA（双方向TVS）をJ402のコイル両端へ並列**。正式採用はまだ行わずX401は維持する。[Littelfuse公式SMBJデータシート](https://www.littelfuse.com/assetdocs/littelfuse_tvs_diode_smbj_datasheet.pdf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)はVRWM33V、VBR36.7〜40.6V、VC53.3V@11.3Aを記載。600Wは規定パルス条件の定格で、連続許容電力ではない。実コイル電流での電圧波形・パルス幅・温度から耐量を照合する。

提示仕様110%を仮のコイル供給上限とすれば26.4V、Q401 OFF時の単純な電圧和は26.4+53.3=79.7V。[Q401 IRLML0100公式資料](https://www.infineon.com/part/IRLML0100)の100V耐圧に対する予備検討値であり、実電源上限・配線サージ・温度条件の保証は含まない。NC接点を開く停止ではコイル上側端子が負側へ振れるため、NC接点間にも供給電圧と逆起電圧の和が掛かり得る。MOSFET OFFとNC開放の両方の経路を確認する。

採用までの残件: コイルLまたはOFF時電流波形から蓄積エネルギーを確認、TVSのパルス幅/繰返し/温度ディレーティング、実装ハーネスでのQ401 VDSとNC接点間サージ、接点解放時間の実測（10ms以内）。コイル近傍の配置を優先検討し、基板設置の場合は配線長によるサージも評価する。

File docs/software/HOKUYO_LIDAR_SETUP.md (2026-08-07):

# Hokuyo USB LiDAR 設定・表示手順

最終確認日: 2026-07-12

mini PCにUSB接続したHokuyo URGシリーズをROS 2 Humbleで使い、RVizで2D走査を表示するための引き継ぎ情報。

## 確認済み構成

| 項目 | 値 |
|---|---|
| LiDAR | Hokuyo Data Flex for USB URG-Series USB Driver |
| 接続 | USB CDC ACM |
| ROS 2 | Humble |
| ドライバ | `urg_node2_nl` |
| ハードウェアID | `00905840` |
| メッセージ型 | `sensor_msgs/msg/LaserScan` |
| トピック | `/scan` |
| frame_id | `laser` |
| 通信QoS | `Best Effort` |
| 実測角度範囲 | 約 -135 deg から +135 deg |
| 表示範囲設定 | 0.1 m から 2.0 m |

Hokuyoは3D点群ではなく、LiDARの高さにおける2Dの距離走査を出力する。RVizでは `PointCloud2` ではなく `LaserScan` 表示を使う。

## USBデバイス名の扱い

USBを抜き差しすると、Linuxの一時的なデバイス名は `/dev/ttyACM0` と `/dev/ttyACM1` の間で変わる。CANableなど他のUSB-CDC機器もあるため、`/dev/ttyACM0` を固定で指定してはならない。

Hokuyo固有の永続パスを使用する。

```text
/dev/serial/by-id/usb-Hokuyo_Data_Flex_for_USB_URG-Series_USB_Driver-if00
```

現在の接続先は次で確認できる。

```bash
ls -l /dev/serial/by-id/usb-Hokuyo_Data_Flex_for_USB_URG-Series_USB_Driver-if00
```

このリンクが `ttyACM0` または `ttyACM1` のどちらを指していても、ROS設定の変更は不要。

## ROSワークスペース側の設定

ROSワークスペースは `/home/tirobot/Harurobo_2025_WS`。

| ファイル | 役割 |
|---|---|
| `src/urg_node2_nl/config/params_serial.yaml` | Hokuyoの永続USBパス、115200 baud、`laser` frameを指定 |
| `src/urg_node2_nl/launch/usb_view.launch.py` | LiDARノードとRVizを同時に起動 |
| `src/urg_node2_nl/config/usb_scan.rviz` | `/scan` のLaserScan表示、`Best Effort` QoS、固定フレーム `laser` |

既存の `urg_node2.launch.py` はEthernet接続の2台構成 (`192.168.0.10` / `192.168.0.12`) 用であり、USB接続のHokuyoには使用しない。

## 起動

```bash
cd ~/Harurobo_2025_WS
source /opt/ros/humble/setup.bash
source install/setup.bash
ros2 launch urg_node2_nl usb_view.launch.py
```

このlaunchでLiDARノードとRVizが起動する。RVizでは赤い点列が表示され、原点の座標軸はLiDAR本体位置を表す。

## RVizで手動設定する場合

1. Fixed Frameを `laser` にする。
2. `Add` から `LaserScan` を追加する。
3. Topicを `/scan` にする。
4. Reliability Policyを `Best Effort` にする。

HokuyoノードはSensorDataQoSでpublishするため、RVizを `Reliable` のままにするとQoS不一致で何も表示されない。

## 動作確認と切り分け

LiDARデータを直接確認する。

```bash
source /opt/ros/humble/setup.bash
source ~/Harurobo_2025_WS/install/setup.bash
ros2 topic echo /scan --qos-reliability best_effort --once
```

正常時の目安:

- `frame_id: laser`
- `angle_min: -2.356...`、`angle_max: 2.356...`
- `range_min: 0.1`、`range_max: 2.0`
- `ranges` に距離値が並ぶ。反射がない方向は `nan` になる。

`/scan` にデータがない場合は、USBを抜き差ししてから永続パスの存在を確認し、上記のlaunchを再起動する。`/dev/ttyACM*` の番号を手で設定ファイルに書き戻さない。

## 表示の読み方

LiDARの出力はカメラ画像ではない。壁は線状、机の脚や人は点の塊として、LiDARの高さで切った断面が見える。今回の設定では最大2 mまでを表示するため、それより遠い物体は表示されない。

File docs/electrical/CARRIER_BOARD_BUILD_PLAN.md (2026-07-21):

# ユニット基板・中央ボード 製作計画

## 参考ボード方針(2026-07-06)

基板製作は、購入済みのMatek CAN-L431と、Matek CAN-G474、ARK CANnode、CANable 2.0を参考に進める。参照範囲と相違点は`CARRIER_BOARD_REQUIREMENTS.md`の「参考ボードと利用範囲」を正本とする。

- CAN-G474実機を主試験機とし、G474、2系統CAN、電源、コネクタおよびカスタムファームを検証する。
- CAN-L431実機は1Mbps CANの配線、終端、コネクタ、対向ノード試験に使う。
- NUCLEO-G474REはCAN-G474で書込み・復旧・必要I/Oに問題が出た場合と、現行ピン設定の回帰確認に使う。
- ARK CANnodeとCANable 2.0は公開回路/BOMから電源、MCU最小構成、CAN、SWD、保護回路を比較する。
- 参考基板と本基板ではMCUパッケージ、CAN系統数、用途、ノイズ環境が異なるため、回路ブロックごとにデータシートで成立性を確認する。

## 共通設計ブロック方針(2026-07-02)

ユニット基板(G474)と中央ボード(Teensy 4.1)は、KiCadの階層シートで共通ブロックを共有する。

| ブロック | 内容 | 使用箇所 |
|---|---|---|
| `can_interface` | `TCAN1051VDRQ1` + `ESD2CAN24DBZRQ1` + 120Ωスライド終端。中央CAN外部接続は横挿しGH 3pin x2(COMM_A/B/GND)、電源は別GH 2pin | ユニット2箇所、中央1〜3箇所 |
| `power_input_5v` | 5V入力 + 逆接保護 | ユニット、中央 |
| `status_led` | 状態LED x3 | ユニット、中央 |
| MCU最小構成 | G474+水晶+SWD+BOOT0(CANable流用) | ユニット。将来の汎用G474 CANノードに転用可 |

リポジトリ構成案:

```text
hardware/
  lib/             共通シンボル・フットプリント
  blocks/          共通階層シート
  unit-board/      G474ユニット基板
  central-board/   Teensy 4.1中央ボード
```

- 共通ライブラリ・ブロックはgit管理し、後続プロジェクトから流用できるようにする。
- 発注はユニット+中央の異種面付けを検討する(製造1回で全基板)。

## フェーズ0: ピン割当確定

やること:

- 主試験機はMatek CAN-G474、NUCLEO-G474REは予備(2026-07-06)。最終搭載はG474RET6自作基板のまま変更しない。
- AF表でFDCAN1(中央CAN)とFDCAN2(C620 CAN)のTX/RXを決め、morphoコネクタに出ていることを確認する。
- SPI SCLK/MISO/MOSIを同じSPIペリフェラルで揃える。
- AMT22は全信号3.3V直結でよい(要件ドキュメント参照)。5Vトレラント要件は不要になった。
- CS、ID DIPスイッチ、LED、デバッグ用GPIOを割り当てる。
- CAN-G474のhwdef(CAN1=PA11/PA12、CAN2=PB5/PB6、SPI2=PB13/PB14/PB15、CS=PB12)と、NUCLEO-G474RE用の現行割当をボード別設定として管理する。

完了条件:

- CubeMXでピン割当が成立する。
- 第二段階の裸チップでも同じピン割当が使える。

## フェーズ1: ブレッドボード / 手配線検証

やること:

- Matek CAN-G474へカスタムファームを書き込み、CAN1/CAN2を同時に1Mbpsで動作させる。
- Matek CAN-L431を中央CANの対向ノードとして接続し、極性、1Mbps通信、終端抵抗、エラーカウンタを確認する。
- NUCLEO単体でAMT22をSPI読み取りする。
- NUCLEOからC620_CANトランシーバ経由でC620通信する。
- 中央CANトランシーバ経由でTeensyとの通信を確認する。
- ID DIPスイッチ読み取りを確認する。
- 5V、3.3V、GNDの安定性を確認する。

完了条件:

- CAN-G474のCAN 2系統が同時に安定動作し、CAN-L431との1Mbps通信、終端・配線条件を記録できる。
- AMT22角度が読める。
- C620 x2へ指令が出る。
- C620フィードバックが読める。
- 低速でステア/駆動が動く。

## フェーズ2: 回路図作成

ブロック:

- STM32G474RET6 + 最小構成(水晶、デカップリング、VDDA、NRST、BOOT0、SWD)
- 中央CANトランシーバ
- 中央CAN終端(`JS102011SAQN`スライドスイッチ、末端ユニットのみON)
- C620_CANトランシーバ
- C620_CAN終端
- TVS(`ESD2CAN24DBZRQ1` x2)
- AMT22コネクタ(全信号直結。分圧なし)
- LDO
- ID用3bit DIPスイッチ(PC6-8、内部プルアップ、ON=GND)
- 状態LED、テストポイント
- 電源入力(5V/GNDのGH 2pin横挿し、CANとは別ハーネス)
- 中央CANパススルーコネクタ(COMM_A/COMM_B/GNDのGH 3pin横挿し x2、基板上でIN/OUT直結)

回路図ルール:

- ネット名は `PAx` / `PBx` を基準にする。
- COMM_A/BとC620_CAN_H/Lを混同しない。
- MCUのC620_CAN_TX/RXをC620_CAN_H/Lへ直結しない。
- 制御GNDと大電流GNDの扱いを明記する。

## フェーズ3: PCB設計

注意:

- 中央CANトランシーバを外部通信コネクタ近くに置く。
- C620_CANトランシーバをC620側コネクタ近くに置く。
- C620_CANスタブを短くする。
- LDOとトランシーバのデカップリングを近くに置く。
- MCUのデカップリングは各VDDピン直近に置く。水晶はMCU直近・短配線・GNDガード。
- SWDヘッダは組付け後もアクセスできる位置に置く。
- AMT22のSPI配線を短くする。
- 終端ジャンパのON/OFF状態がシルクで分かるようにする。
- ID DIPスイッチのビット意味をシルクで分かるようにする。

## フェーズ4: 初回実装

初回は全機能を一気に載せず、段階的に確認する。

1. 電源系だけ実装して5V/3.3V確認。
2. MCU+最小構成を実装し、SWDでDevice ID認識 → LED点滅で起動確認。
3. 中央CANトランシーバを実装してTeensyとの通信確認。
4. C620_CANトランシーバを実装してC620通信確認。
5. AMT22まわりを実装してSPI確認。
6. ID DIPスイッチを確認。
7. C620 x2と接続して低速動作確認。

## フェーズ5: 実機検証

ログ項目:

- 5V電圧
- 3.3V電圧
- 中央通信エラー
- C620_CANエラー
- AMT22読取エラー
- C620フィードバック有無
- モーターrpm指令
- ステア角
- ユニットID

合格条件:

- 起動時に全ユニットIDが識別できる。
- 各ユニットのAMT22が読める。
- 各C620が応答する。
- E-stop時にモーター電源が遮断される。
- 通信断時に安全停止へ移行する。

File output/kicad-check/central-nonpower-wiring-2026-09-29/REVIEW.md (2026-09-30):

# Central nonpower wiring — 2026-09-29

Scope and results: [design record](../../../docs/electrical/CENTRAL_NONPOWER_WIRING_2026-09-29.md).

Before snapshot is under `before/central-board-placement/`. `before.net` / `after.net` are KiCad exports, `expected-pins.json` is the migration pin contract, `audit.json` contains the independent connector / Teensy / preserved-sheet checks. `before-erc.rpt` / `after-erc.rpt` use the existing project rules without changing exclusions.

ERC 193 → 4; four remaining errors are power-pin drive declarations in excluded CAN sheets. Safety TBDs are still unresolved even when ERC is clear. X401/X402 are functional placeholders with no selected device/footprint; X402 does not join its three nets.

Rendered SVG/PNG files are visual QA, not a fabrication release. No PCB or firmware changes.

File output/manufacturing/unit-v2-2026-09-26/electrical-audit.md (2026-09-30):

# 駆動V2 独立電気監査 — 2026-09-26

> 監査後ユーザー確認: J6逆順はケーブル都合による意図した配列。R13=33k/R14=22kも次回調達・実装値として確定。下記の2点の未確認判定は解消し、V2資料へ反映。回路/ZIPは元から一致しており変更不要。C620外部終端等は引き続き未確認。

対象: `hardware/unit-board-v2/` の保存済み回路図（2026-09-25 22:55）とPCB（監査開始時2026-09-26 16:05）。元データを編集せず、KiCad XML netlistを `tmp/pdfs/unit_v2_latest_2026-09-26.xml` へ独立出力して照合した。DRC・全pad/copper接続照合・製造出力は別担当。以下は回路図ネットの確認であり、実機動作の保証ではない。

## 合格項目

| ブロック | 実際のRef/pin/netと照合結果 |
|---|---|
| MCU電源 | U4 STM32G474RET6: VBAT1、VDD16/32/48/64=`/VTREF_3V3`、VSS15/31/47/63とVSSA27=GND。ネット名VTREFでもLDO U2 OUTと同じデジタル3.3Vレールで、アナログVREF+とは分離されている。 |
| アナログ電源 | U4 VDDA29=`VDDA_A`、FB1 BLM18AG601SN1D経由3.3V、C13 100nF＋C11 1uF。VREF+28=`VREF_PLUS`、R2 0ΩでVDDAへ、C12 10nF＋C14 1uF。 |
| MCUデカップリング | C5/C6/C7/C8/C9各100nFがデジタル3.3V/GND、C10 4.7uFが同レール。各VDD/VBATの個別容量数を満たす。物理的な近接と帰路はPCB担当の確認対象。 |
| Reset/Boot | U4 PG10/NRST7→C15 100nF/GNDとJ8-10。PB8/BOOT0 pin61→R4 10k/GND。HSEはPF0 pin5、PF1 pin6、Y1 FC3BAEBDI8.0-T1の発振端子1/3、ケース2/4=GND、R3 0ΩとC3/C4 10pFを使用。 |
| 保護5V/3.3V | U1 LM66100: pin1=入力5V、2=GND、3 CEと6 VOUT=保護5V。U2 TLV76133DCYR:1 GND、2 OUT=3.3V、3 IN=保護5V。SOT-223 tabもpad2。 |
| 中央CAN | U3 TCAN1051VDRQ1:1 TXD→U4 PA12 pin46、4 RXD→PA11 pin45、2/8=GND、3 VCC=保護5V、5 VIO=3.3V、7 CANH=`COMM_A`、6 CANL=`COMM_B`。C1/C2各100nF、D1 ESD2CAN24 pins1/2=バス、3=GND。J2/J3とも1=A、2=B、3=GND。R1 120Ω＋SW1を持つ。 |
| C620 CAN | U5:1 TXD→U4 PB13 pin35、4 RXD→PB12 pin34、2/8=GND、3 VCC=保護5V、5 VIO=3.3V、7=H、6=L。C17/C18各100nF、D2 TVS pins1/2=H/L、3=GND。J4/J5とも1=H、2=L、3=GND。 |
| SWD/UART | 現在のSWDは **J8** Samtec FTSH-105-01-L-DV-K-P。1=デジタル3.3V、2=SWDIO→U4-49、3/5/9=GND、4=SWCLK→U4-50、6=SWO→U4-56、7/8=NC、10=NRST→U4-7。J9:1 GND、2 TX→U4 PA2-14、3 RX→PA3-17。SWDのPCB側DNPは電気ネット不良でなく組立属性の不一致として別途修正する。 |
| 5Vクランプ接続 | D7 BAT54S-HF:1 GND、2 3.3V、3 ADC→U4 PA0-12。C16 10nF→GND。上下レールへのseries Schottky clamp接続を保持。 |
| 主要footprint銅箔 | PCB内U1 SOT-363、D2/D7 SOT-23、SW3 DIP、J6 GH6についてpad番号・局所座標・寸法をKiCad10標準と比較し一致。library mismatch警告をpad形状不良と混同しない。 |

MCUのピン位置は[ST STM32G474RE datasheet](https://www.st.com/resource/en/datasheet/stm32g474re.pdf)、CANのV suffix/VIO/SとSOIC pin配列は[TI TCAN1051 datasheet](https://www.ti.com/lit/ds/symlink/tcan1051-q1.pdf)、LM66100 CE→VOUTのreverse-current接続は[TI LM66100 datasheet](https://www.ti.com/lit/ds/symlink/lm66100.pdf)、LDO配列は[TI TLV761 datasheet](https://www.ti.com/lit/gpn/tlv761)と照合した。Comchip BAT54S-HFのメーカー一次資料URLは現サイトへリダイレクトするため、正式採用品のseries pin配列と標準pad一致までの確認とし、購入現物の型番/markingは実装前確認事項。

## 確定した資料・組立条件の不一致

1. **5V監視定数:** 回路図はR13 `RC0603FR-0733KL 33k`（5V側）、R14 `RC0603FR-0722KL 22k`（GND側）。現要件/9月21日部品選定の22k/10kと異なる。実回路の分圧率は0.4、5Vで2.000V、5.5Vで2.200V、換算倍率2.5。22k/10kなら率0.3125、5Vで1.5625V、倍率3.2。どちらも通常5V監視として動作し得るが、BOM・実装値・ファーム換算を同じ側へ統一する。元データを推測で変更していない。部品選定書下部にも旧33k/22kの計算文が残り、内部矛盾がある。
2. **AMT22基板側配列:** J6実ネットは **1=CS、2=MISO、3=GND、4=MOSI、5=SCLK、6=5V**。R18/R17/R16/R15各0Ωを介しU4 PD2-55/PC11-53/PC12-54/PC10-52へ接続。現CARRIER要件のGH表、および[Same Sky AMT22 sensor datasheet](https://www.sameskydevices.com/product/resource/amt22.pdf)のセンサ配列1=5V、2=SCLK、3=MOSI、4=GND、5=MISO、6=CSとは逆順。基板とセンサ間の変換ハーネスを逆番号で正しく結線するなら成立するが、「ストレート結線」の旧資料のままでは誤配線する。ユーザーの意図と変換ハーネス対応表を確認してからReleaseとする。GH嵌合面/基板面の見かけの左右反転と実pad番号を混同しない。

## 未確認・Release前に区別する項目

- **C620物理終端:** 今回のnetlistにはC620バス終端R/SWの新追加なし。基板不備とは断定しない。`C620①─駆動基板─C620②` の物理両端へ外部120Ωがあるなら中央の駆動基板へ追加終端は不要。C620内蔵/外部終端と実ハーネスを未測定。電源OFFで両端のみ終端、H-L間約60Ω、片側約120Ωを確認する。
- **SWDケーブル嵌合:** Samtec -K notchとactual cable/adapterのpin1視点、pin7 blocked-holeの有無、STDC14→MIPI10変換を機構照合する。10pinの電気配列だけで付属ケーブルとの互換を断定しない。
- **部品/起動評価:** LM66100 ST pin5は未使用NC（TIは未使用時GNDを推奨）、HSE負荷容量/drive level、LDO温度/容量実効値、購入現物のMPN/方向は実機段階で確認。未使用open-drain STはこの監査で確定した機能不良とは判定しない。
- GPIO/SPI/CAN電気配列は一致するが、実測・CSS/HSI fallback・SPI待ち時間・ファーム5V換算・GND帰路をこのread-only netlist監査だけで合格にしない。

**判定:** MCU電源/Reset/CAN/SPI信号のネット接続に新しい確定断線は検出していない。5V監視の採用定数とAMT22変換ハーネスを統一し、外部終端条件を確定するまで、製造ZIPは検討用/NOT_RELEASEDとして扱う。

## 2026-09-26 C620終端のユーザー確認

2個のGHポートから各ESCへ接続し、各ESCの120Ω終端をONにする構成で確定。ESC①―駆動基板―ESC②の両端終端なので、C620用の基板内終端なしは設計意図に一致し不具合ではない。J6逆順・33k/22k分圧・外部終端の3確認事項はすべて解消。回路/PCB/ZIPは変更不要。電気的ERC/DRCエラー・未接続は0。残るライブラリ/シルク/実装属性・ケーブル機構確認を、この構成確認だけで合格に変更しない。

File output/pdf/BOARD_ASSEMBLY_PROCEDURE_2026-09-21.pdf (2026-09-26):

差動ステア 駆動基板 / オドメトリ基板 実装作業手順書 | p.1 / 9
Differential Swerve Drive / 基板実装手順書 2026-09-21 基板: 有鉛HASL ハンダ: Sn63Pb37 (融点183C 有鉛) | 生成: tmp/assembly/build_assembly_procedure.py

# 基板実装 作業手順書

### unit-board RevA (駆動モジュール) / odometry-board RevA (ODOM) 2026-09-21

## 着手前に必ず片付ける3件（詳細 p.2）

1. ODOM基板の U3 / U7 / U9 (74LVC2G17) は pad2=GND・pad5=VCC が基板上で未接続。3輪分のエンコーダ入力が全滅するためジャンパ必須 (施工図 p.5)
2. 基板は有鉛HASL。Sn63Pb37 とは最良の相性だがパッドが平坦でないため、LQFP64 (0.5mmピッチ) で印刷ブリッジが出やすい。印刷直後のルーペ確認を必須にする (p.2 / p.3)
3. DIPスイッチが発注時に別形状へ置換 (A6S-3104-H → DS04-254-1-03BK-SMT)。ペースト印刷前に裸基板で仮置きしてランド一致を確認する

## 対象基板

| 駆動(unit)基板 | オドメトリ(ODOM)基板
外形 / 構成 | 45.0 x 45.0 mm / 4層 1.6mm 内層GNDプレーン | 65.0 x 27.5 mm / 4層 1.6mm 内層GNDプレーン
MCU | STM32G474RET6 (LQFP-64 0.5mmピッチ) | STM32F405RGT6 (LQFP-64 0.5mmピッチ)
実装面 | 表面のみ / THTパッド 0個 | 表面 + THTコネクタ J4・J5・J6 (XH4) / J7 (XH8)
枚数 | 4枚 (実機3 + 予備1) | 1枚 (unitId=4)
配置図 | p.8 (output/assembly/unit-board-placement-refdes.pdf) | p.9 (output/assembly/odometry-board-placement-refdes.pdf)
座標CSV | output/fabrication/unit-board-revA/unit-board-position.csv | output/assembly/odometry-board-position.csv

## この手順書の使い方

・ 回路図は「向き・極性・その部品が何者か」を調べる二次資料。実際に部品を載せる位置は p.8 / p.9 の配置図と座標CSVを見る。
・ p.8 / p.9 をA3で印刷し、載せた部品を1個ずつ塗り潰していくと取り違えが起きない。DNP(未実装)部品には×印が入っている。 ・ チェックボックス付きの手順 (p.4 / p.6) は、基板1枚ごとに1部プリントして使う。

1. 着手前に必ず片付ける3件 | | | p.2 / 9

## 1-1. ODOM基板 U3 / U7 / U9 の電源が基板上で未接続 [要ジャンパ]

発注に使ったGerber生成元コミット bcd22f1 (2026-07-29) の Oddom board.kicad_pcb を機械検査した結果、74LVC2G17 を3個とも pad2 (GND) と pad5 (VCC) にネットが割り当たっていない。 2026-07-26 に回路図側で電源ユニットを追加した修正が PCB へ Update PCB from Schematic されないまま製造データが出ている。届いた実基板も同じ状態のはず。
・ 影響: AMT102 は J4/J5/J6 の pin1 = PWR_5V で 5V 駆動。その A/B 出力を 3.3V 側へ受け直すのがこのバッファなので、未対策だと3輪ともエンコーダが読めない。
・ KiCad DRC の「unconnected pads 0」はネットが付いていないパッドを検出しないため、DRCレポートでは気付けない。
・ 対処: リフロー後・洗浄前に 0.1mm ポリウレタン線でジャンパ (施工図 p.5)。実基板でテスターで先に確認すること。

## 1-2. 表面処理 有鉛HASL とステンシル印刷

届いた基板の表面処理は有鉛HASL (確認済み)。Sn63Pb37 とは同じ有鉛系で、濡れの点では最良の組み合わせ。合金の相性を気にする必要はない。注意すべきなのは、HASL のパッドが平坦でないこ と。
・ パッド上にハンダの盛りがあるため、ステンシルが浮いてペーストが横へ逃げる。0.5mmピッチの LQFP64 (U4 / U1) でブリッジが出やすい。
・ 対策: 同厚の捨て基板で基板の四方を囲ってステンシルを浮かせない / スキージは45°で1回・押しつけすぎない / 印刷直後にルーペでパッド間を確認し、繋がっていたら拭き取って印刷し直す。 ・ 逃げ道: ブリッジが続くなら LQFP64 だけドラッグはんだで手付けする (p.3 の 2-3)。有鉛 + HASL はドラッグはんだが最もやりやすい組み合わせ。

## 1-3. 置換部品の現物照合

2026-09-07 の発注で4点を置換した。.kicad_pcb の Value は更新済みだが footprint は旧品のまま。特にDIPスイッチは別メーカー・別形状。

図面(BOM)上の型番 | 実際に届いた型番 | 判定 | 確認内容
TLV1117LV33DCYR | TLV76133DCYR | OK | SOT-223-3、1=GND / 2=OUT(タブ) / 3=IN で同一。確認済み
ECS-80-8-33Q-JES-TR | FC3BAEBDI8.0-T1 | 要目視 | 3225 4pad・CL=8pF で同一。1番マークの向きだけ実装時に確認
BAT54SLT1G | BAT54S-HF | OK | SOT-23、直列2素子・30V/200mA で同一。確認済み
A6S-3104-H | DS04-254-1-03BK-SMT | 要実測 | 別メーカー別形状。裸基板へ仮置きしてランド一致を確認。合わなければ今回は未実装にし、ユニットIDはフ ァーム定数で逃がす (PC6-PC8 内部プルアップ、未実装=全bit High)

2. Sn63Pb37 (183℃) のリフロープロファイルとホットプレート運用 | p.3 / 9

## 2-1. 温度プロファイル

プレートの表示温度 ≠ 基板温度。両基板とも4層1.6mm・内層GNDプレーン持ちなので、基板表面は表示より 10〜20℃ 低く出る。可能なら熱電対を基板の端の空きランドにカプトンで貼り、基板側 の温度を見る。以下の「基板温度」が正、「プレート設定」は目安。

段階 | 基板温度 | プレート設定 (目安) | 時間 | ねらい / 見どころ
予熱・ソーク | 130 〜 150 ℃ | 150 〜 165 ℃ | 90 〜 120 秒 | フラックス活性化と基板全体の均熱。ここを急ぐとボール化・ツームストーンが出る。一番の勘所
昇温 | 150 → 183 ℃ | 設定を段階的に上げる | 30 〜 60 秒 | 昇温は 1〜3 ℃/秒。一気に上げない
リフロー(ピーク) | 200 〜 215 ℃ | 215 〜 230 ℃ | 183℃超えで 45〜75 秒 | 一斉に銀色へヌルッと濡れる。濡れてから 10〜20 秒保持して降ろす
上限 | 225 ℃ を超えない | - | - | 有鉛なので 230℃ 以上にする理由が無い。無駄な熱ストレスとフラックス枯れを招くだけ
冷却 | 自然冷却 | プレートから金属板へ移す | - | 送風・急冷しない。冷えるまで基板を動かさない

## 2-2. ホットプレート運用のコツ

・ 基板はプレート中央に、全面が接地する位置へ置く。端がはみ出すと片側だけ溶けない。
・ 予熱で一旦保持してから段階的に上げる2段運用が確実。ダイヤルを一気に回さない。
・ 「一斉に銀色にヌルッと濡れる」瞬間がリフロー。そこから10〜20秒待って降ろす。不安で長く置くとフラックスが枯れてボール化する。 ・ ピンセットで部品を押さない。多少ずれていてもセルフアライメントで揃う。
・ 有鉛は濡れが速く、仕上がりは光沢のある滑らかなフィレットになる。白く曇る / ザラつく場合は温度不足か加熱しすぎを疑う。

## 2-3. 逃げ道: LQFP64 をドラッグはんだで付ける

HASL の凹凸でステンシル印刷がどうしてもブリッジする場合、U4 (unit) / U1 (ODOM) だけ手付けに切り替えてよい。有鉛ハンダ + HASL はドラッグはんだが最もやりやすい組み合わせで、ステン シルで苦戦するより速い。
・ 手順: 対角2ピンを仮固定して位置を出す → フラックスをたっぷり塗る → C型こて先にハンダを少量乗せ、1辺をゆっくり引く → 余剰は吸い取り線で取る → 全辺を繰り返す。
・ ブリッジは「失敗」ではなく前提。最後に吸い取り線でまとめて取れば良い。フラックスをケチらないことが唯一のコツ。
・ その場合、LQFP64 のパッドはステンシル印刷時に拭き取っておくか、印刷せずに他部品だけ先にリフローしてから手付けする。

## 2-4. 手はんだにする部品（両工法共通）

部品 | | 工法
ODOM の THT: J4 / J5 / J6 (XH 4pin) / J7 (XH 8pin) | リフロー対象外。リフロー後に糸ハンダで手付け
GHコネクタ・SW1・SW3 (SMD) | リフローで付けてよい。有鉛なので脆さの心配はない。ただし取付脚(MP)は太いので、フィレットが痩せていたら手で足す

3. 実装手順（基板1枚ごとにこのページを1部使う） 基板名: ____________ シリアル: ______ 日付: __________ | p.4 / 9

## STEP 1-3 検査・仮合わせ・印刷

裸基板を目視。傷・打痕・レジスト欠け・パッドの酸化がないか。
テスターで 5V-GND間 / 3V3-GND間 が短絡していないことを確認 (裸基板なのでどちらも開放が正常)。
【ODOMのみ】U3 / U7 / U9 の pin5-3V3 間、pin2-GND 間の導通を確認。導通なし = p.5 のジャンパが必要 (想定どおり)。 DIPスイッチ DS04-254-1-03BK-SMT、GHコネクタ、水晶、LQFP64 を裸基板へ仮置きし、ランドと足が一致することを確認。 ステンシル印刷: 同厚の捨て基板で四方を囲って基板を固定 → スキージ45°で1回引く → ステンシルを真上へ持ち上げる。 印刷直後にルーペで確認。特に LQFP64 (U4 / U1) のパッド間でペーストが繋がっていないか。繋がっていたら拭き取って印刷し直す。 【LQFP64を手付けにする場合 (p.3 の 2-3)】U4 / U1 のパッドに乗ったペーストは綿棒+IPAで拭き取っておく。

## STEP 4 部品搭載

配置図 (p.8 / p.9) を見ながら、背の低い受動部品 → IC → 残り の順に置く。載せたら図面を塗り潰す。
極性・向きを毎回確認: LED (D6 / D8 / D9 / D10 のカソードマーク)、D1 / D2 / D7、U1〜U5 の1番ピン、水晶 Y1 の1番マーク。 LQFP64 はパッケージの1番ピンドットと基板シルクの1番マークを合わせ、四辺の足がランド中央に来るよう微調整する。 ピンセットで部品を押し込まない。多少ずれていてもセルフアライメントで揃う。

## STEP 5-8 リフロー・THT・ジャンパ・検査

ホットプレート中央に基板全面が接地するよう置き、p.3 のプロファイルでリフロー。濡れてから10〜20秒で金属板へ移し自然冷却。 【ODOMのみ】THTコネクタ J4 / J5 / J6 / J7 を手はんだ。
【LQFP64を手付けにする場合】フラックス＋ドラッグはんだで U4 / U1 を実装し、吸い取り線でブリッジを除去。
【ODOMのみ】p.5 に従って U3 / U7 / U9 の電源ジャンパを施工し、導通・絶縁を確認。
IPAでフラックス除去 → 完全乾燥。
ルーペで全ピン検査: LQFP64 のフィレット形成、ブリッジ、未濡れ、ツームストーン、ずれ。有鉛なので光沢のある滑らかなフィレットが正常。白く曇る・ザラつく場合は加熱不足か加熱し すぎ。
テスターで再測定: 5V-GND / 3V3-GND が短絡していないこと。3V3-5V 間も短絡していないこと。

4. ODOM基板 U3 / U7 / U9 電源ジャンパ 施工図 | p.5 / 9

## 4-1. 74LVC2G17 (SOT-23-6) のピンと必要な配線

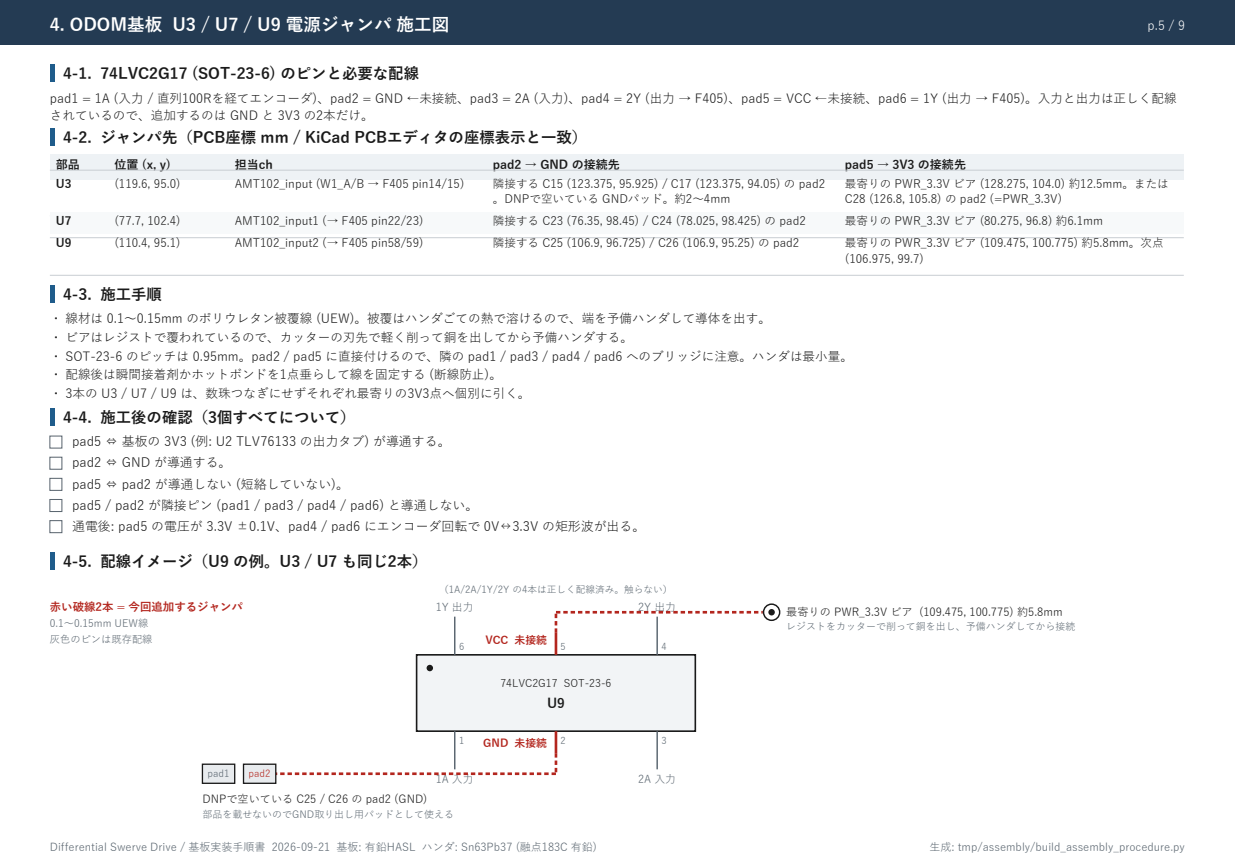
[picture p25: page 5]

pad1 = 1A (入力 / 直列100Rを経てエンコーダ)、pad2 = GND ←未接続、pad3 = 2A (入力)、pad4 = 2Y (出力 → F405)、pad5 = VCC ←未接続、pad6 = 1Y (出力 → F405)。入力と出力は正しく配線
されているので、追加するのは GND と 3V3 の2本だけ。
4-2. ジャンパ先（PCB座標 mm / KiCad PCBエディタの座標表示と一致）

・ 線材は 0.1〜0.15mm のポリウレタン被覆線 (UEW)。被覆はハンダごての熱で溶けるので、端を予備ハンダして導体を出す。
・ ビアはレジストで覆われているので、カッターの刃先で軽く削って銅を出してから予備ハンダする。
・ SOT-23-6 のピッチは 0.95mm。pad2 / pad5 に直接付けるので、隣の pad1 / pad3 / pad4 / pad6 へのブリッジに注意。ハンダは最小量。
・ 配線後は瞬間接着剤かホットボンドを1点垂らして線を固定する (断線防止)。
・ 3本の U3 / U7 / U9 は、数珠つなぎにせずそれぞれ最寄りの3V3点へ個別に引く。
4-4. 施工後の確認（3個すべてについて）

pad5 ⇔ 基板の 3V3 (例: U2 TLV76133 の出力タブ) が導通する。
pad2 ⇔ GND が導通する。
pad5 ⇔ pad2 が導通しない (短絡していない)。
pad5 / pad2 が隣接ピン (pad1 / pad3 / pad4 / pad6) と導通しない。
通電後: pad5 の電圧が 3.3V ±0.1V、pad4 / pad6 にエンコーダ回転で 0V↔3.3V の矩形波が出る。

5. 通電・bring-up 手順 実装は一括、通電は段階的に | p.6 / 9

## 5-1. 駆動(unit)基板

# | 手順 | 合格条件 / 備考

1 | 電流制限つき電源で 5V を J1 へ投入。制限はまず 100mA。 | 制限に張り付いたら即遮断してショート探し。正常なら数十mA以下
2 | 3.3V を測定 (U2 TLV76133 出力 / TP)。指で各ICの発熱を確認。 | 3.25 〜 3.35V。熱い部品があれば即遮断
3 | SWD (J7) を ST-Link へ接続し Device ID を読む。 | STM32G474 として認識されること
4 | 既存ファームを書き込み、LED点滅を確認。 | 現行ファームは HSI 16MHz 動作 かつ LED_RUN = PA5 で NUCLEO と同じピンなので、水晶が動かなくてもこ こまで確認できる
5 | 水晶 Y1 (8MHz) の発振開始と周波数を確認。 | HSE を使う設定に切り替えてから。FC3BAEBDI8.0-T1、CL=8pF
6 | 中央CAN (FDCAN1) → C620 CAN (FDCAN2) の順に 1Mbps 通信を確認。 | 終端スライドスイッチ SW1 は末端ユニットのみ ON
7 | AMT22 SPI 読み取り、ID用DIPスイッチ SW3 を確認。 | SW3 未実装ならファーム定数でIDを与える
8 | C620 x2 を接続し、車輪を浮かせた状態で低速動作。 | docs/testing の手順に従う。E-stop が効くことを先に確認

## 5-2. オドメトリ(ODOM)基板

# | 手順 | 合格条件 / 備考

1 | 同じく 100mA 制限で 5V 投入 → 3.3V 測定。 | 3.25 〜 3.35V
2 | SWD (J8) で STM32F405 の Device ID を読む。 | F405 用のファームはまだ未着手。まず ID 認識と LED 点滅を作る必要がある
3 | U3 / U7 / U9 の pad5 が 3.3V になっていることを確認。 | p.5 のジャンパが効いているか

4 AMT102 を1本だけ J4 に挿し、バッファ出力 (pad4 / pad6) を観測しながら手で回す。 0V ↔ 3.3V のきれいな矩形波。チャタリングが出るなら DNP の入力フィルタ C15/C17 等の実装を検討

5 | 3本とも同様に確認 → TIM2 / TIM3 / TIM4 のエンコーダモードでカウント。 | STM32F405_ODOMETRY_PIN_ASSIGNMENT.md が正本
6 | 中央CANへ x/y/θ を配信。 | unitId = 4

6. 参照情報・極性確認リスト | p.7 / 9

## 6-1. 向き・極性に注意する部品

RefDes | 部品 | 確認内容
U4 (unit) / U1 (ODOM) | STM32 LQFP-64 | パッケージ隅の1番ピンドットと基板シルクの1番マークを合わせる
U1 (unit) / U5 (ODOM) | LM66100 SC-70-6 | 極小。1番ピンマークとシルクを拡大鏡で照合
U2 | TLV76133 SOT-223 | タブが2番 (OUT)。タブ側の向きでしか入らないので実質誤装着しない
U3 / U5 (unit), U4 (ODOM) | TCAN1051V SOIC-8 | 1番ピンのくぼみ
U3 / U7 / U9 (ODOM) | 74LVC2G17 SOT-23-6 | 1番ピンマーク。+ p.5 のジャンパ
Y1 | FC3BAEBDI8.0-T1 3225 4pad | 1番マーク。信号pad 1/3、GND pad 2/4
D6 / D8 (緑), D9 (黄), D10 (赤) | LTST-C190 系 0603 LED | カソードマーク。色の入れ違いにも注意
D1 / D2 | ESD2CAN24 SOT-23 | 1番ピン
D7 (unit) | BAT54S-HF SOT-23 | 直列2素子。向きあり
D2 / D3 / D4 (ODOM) | TVS SOT-23 | 向きあり

## 6-2. ODOM基板のDNP (今回は実装しない部品)

C15 / C17 / C23 / C24 / C25 / C26 は未購入・未実装。配置図では×印が入っている。これらはエンコーダ入力のRCフィルタ用で、直列100Rだけで運用を始める。ノイズで誤カウントする場合に後 から実装を検討する。なお p.5 のジャンパでは、この空いたパッドの GND 側を接続先として使う。

## 6-3. 関連ファイル

用途 | パス
配置図 (RefDesのみ / 作業用) | output/assembly/unit-board-placement-refdes.pdf, output/assembly/odometry-board-placement-refdes.pdf
配置図 (値つき / 照合用) | output/assembly/unit-board-assembly-top.pdf, output/assembly/odometry-board-assembly-top.pdf
実装座標CSV | output/fabrication/unit-board-revA/unit-board-position.csv, output/assembly/odometry-board-position.csv
BOM | output/fabrication/unit-board-revA/unit-board-jlcpcb-bom.csv, output/procurement/odometry-board-raw-bom.csv
回路図 (人間レビュー用PDF) | docs/electrical/UNIT_BOARD_SCHEMATIC_WITH_BOM.pdf, docs/electrical/ODOMETRY_BOARD_SCHEMATIC_WITH_BOM.pdf
ピン割当の正本 | docs/electrical/CARRIER_BOARD_REQUIREMENTS.md, docs/electrical/STM32F405_ODOMETRY_PIN_ASSIGNMENT.md
この手順書の生成スクリプト | tmp/assembly/build_assembly_procedure.py

# REF**

J6

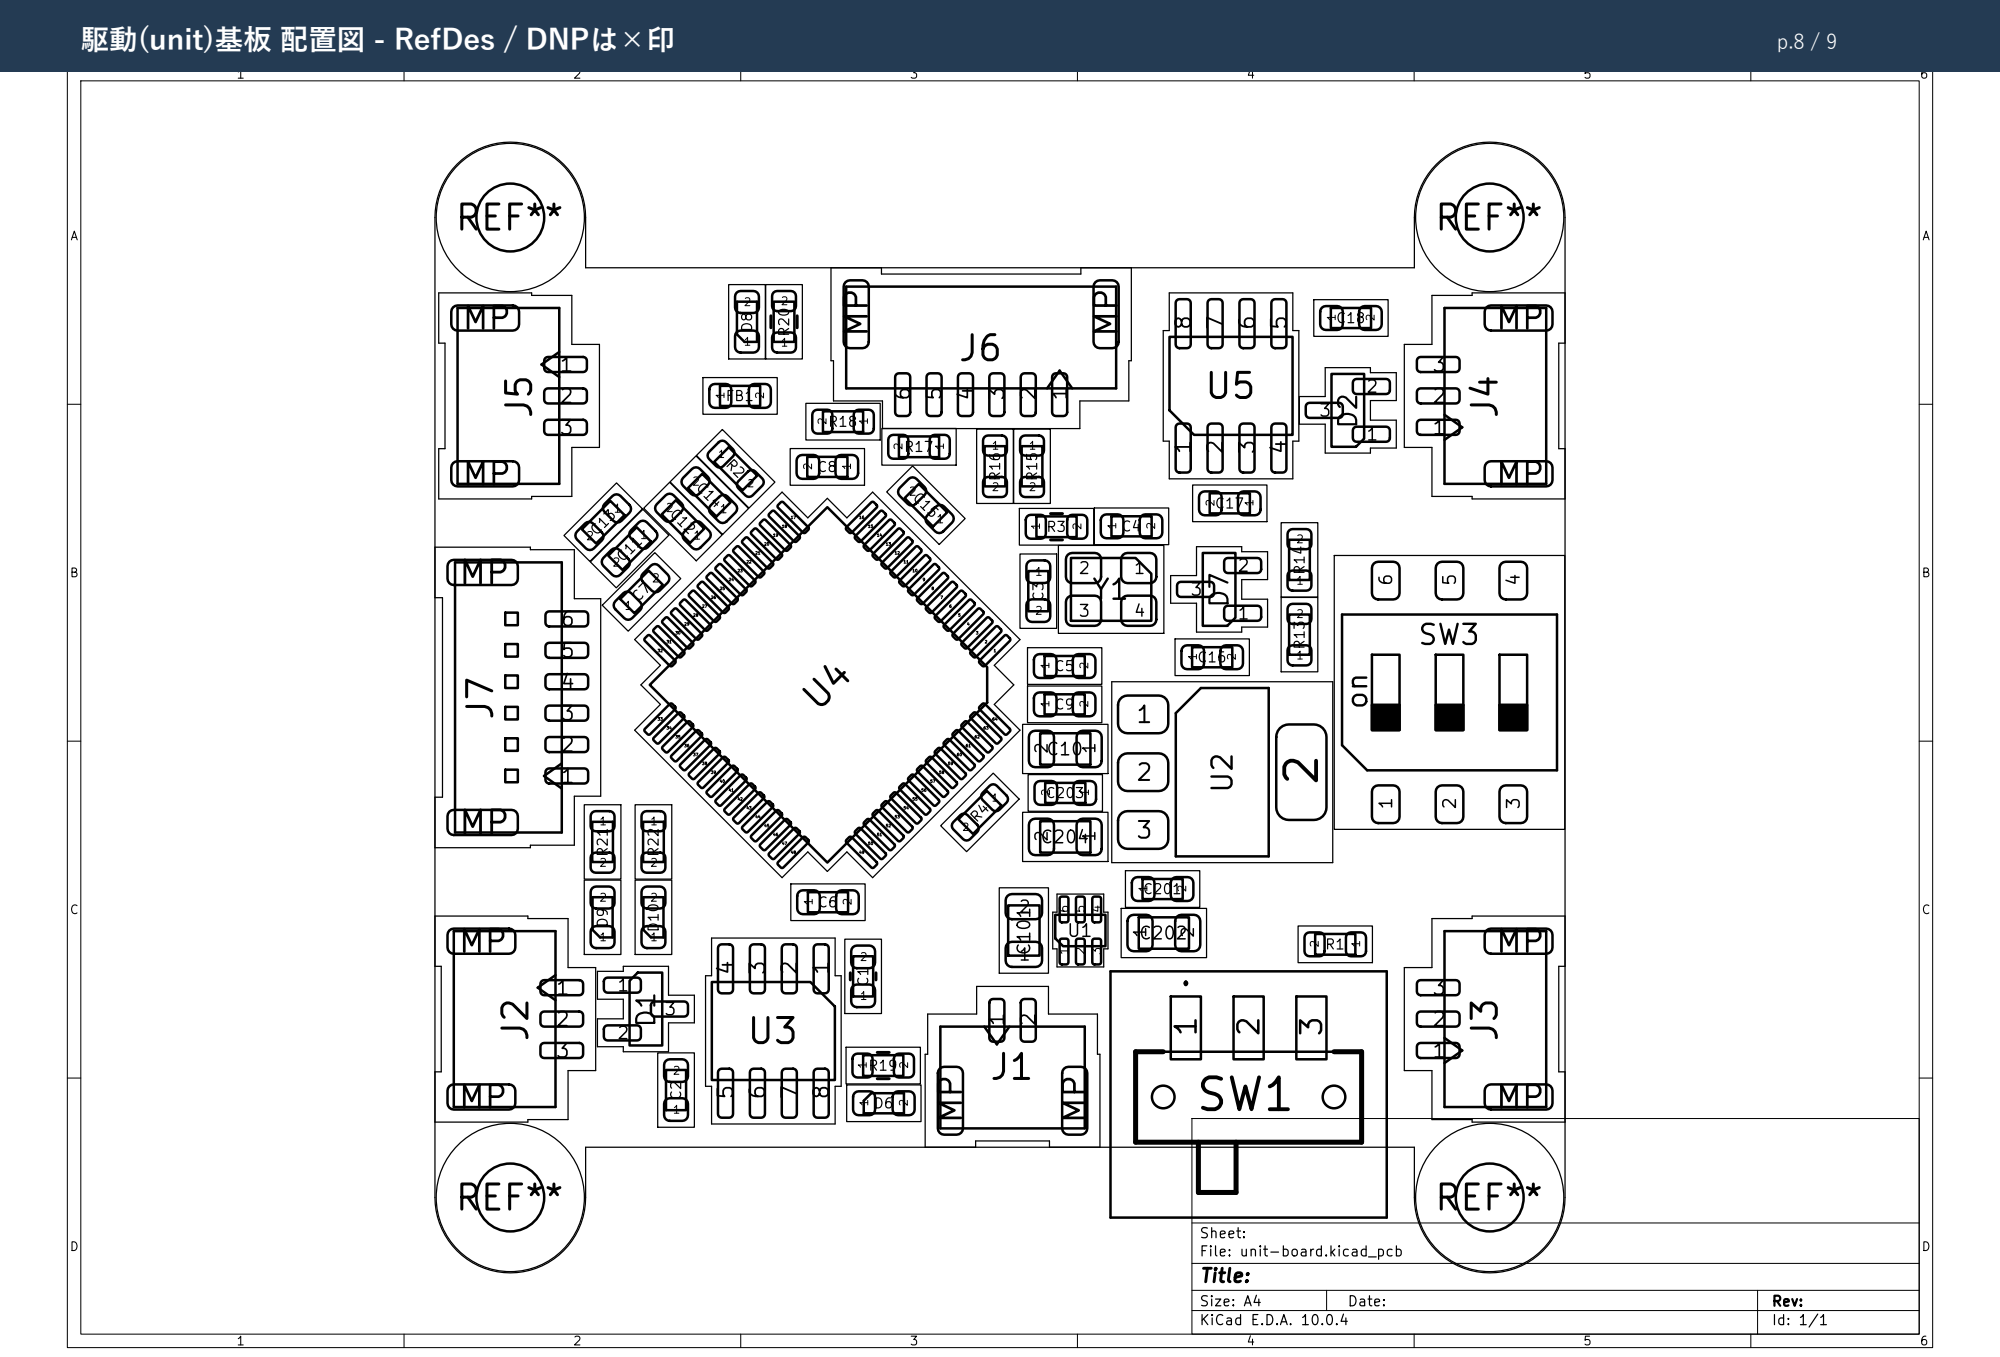
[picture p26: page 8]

オドメトリ(ODOM)基板 配置図 ‑ RefDes / DNPは×印 | p.9 / 9

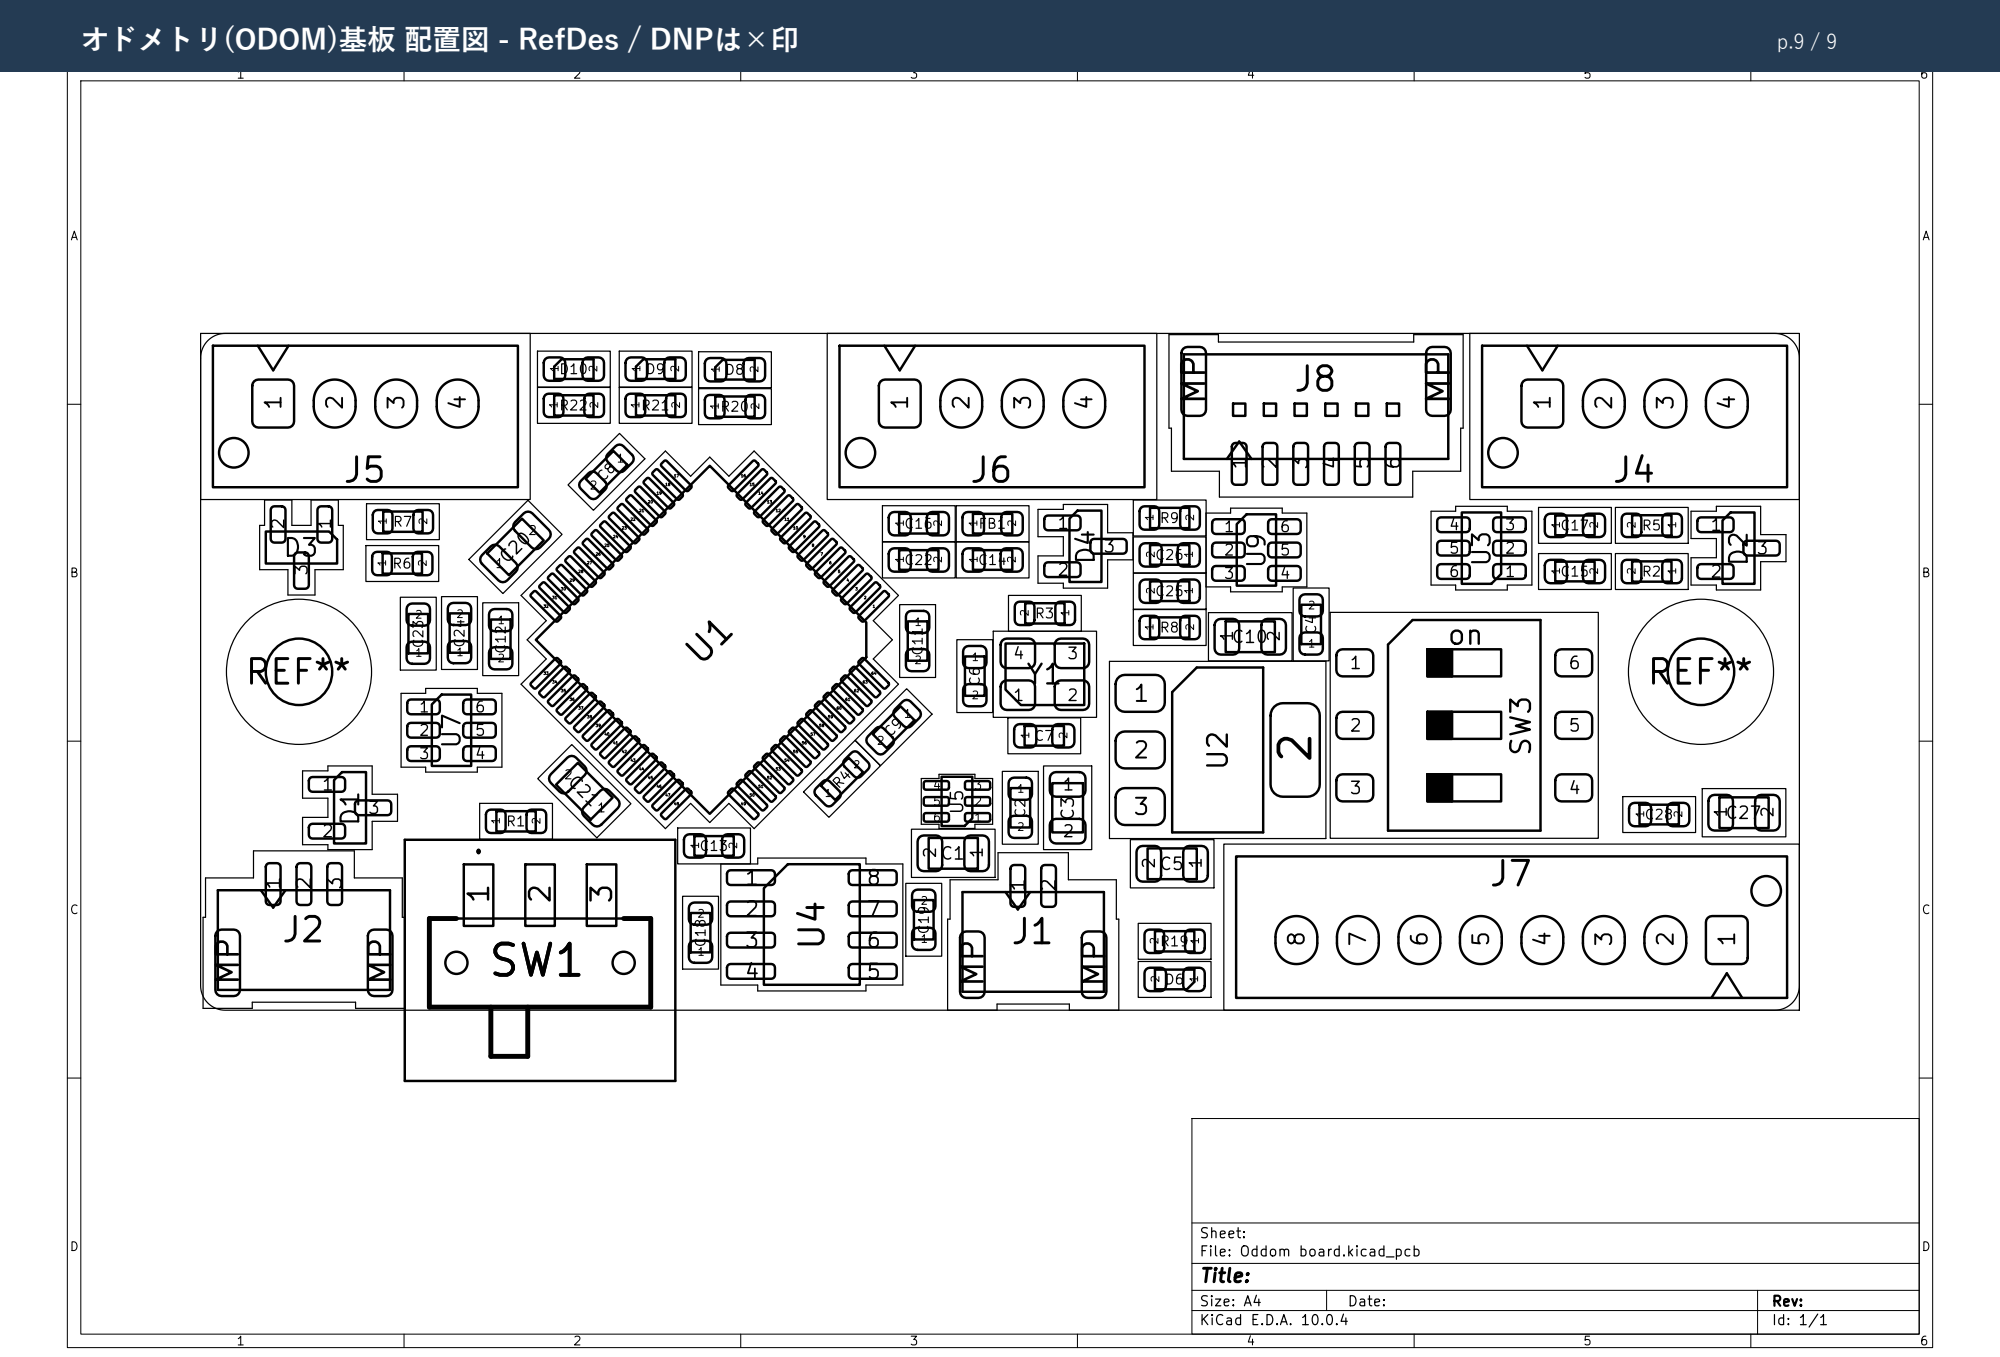
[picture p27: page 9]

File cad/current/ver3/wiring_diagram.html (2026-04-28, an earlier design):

# ロボコン機体 配線図

4S LiPo / LM2596 / Teensy 4.0 / ESP32 / C610×2 / M2006×2 / DualSense BT

### 配線時の重要ポイント

- GND一点接地: モータGND (バッテリー−) とロジックGND (LM2596 OUT−) は必ずバッテリー側で一点接地。LM2596の入力GNDと出力GNDは基板内部で繋がっている。
- LM2596の出力電圧調整: Teensy/ESP32を接続する前に、無負荷でテスターで5.00V ±0.05V を確認してから接続。初期状態の電圧は不定。
- Teensy 4.0のUSB-VINパッド: 裏面の2つのパッドを繋ぐ細いトレースをカッターで切る。これを怠ると、開発中にUSBとVIN(5V)が競合して最悪Teensyが壊れる。
- CAN終端抵抗: CANバスの両端のうち片方に120Ω抵抗 (CANH-CANL間)。もう片端のC610は内部終端があると言われているので片方だけでよい場合もあり。実機で要確認。
- C610のCAN ID: C610のDIPスイッチで #1=0x201, #2=0x202 に設定。制御コマンドは0x200に全8バイトまとめて送信。
- 電源投入順: バッテリー接続→メインSW ON でモータ電源とロジック電源がほぼ同時に立ち上がる。起動後1-2秒はTeensyからCANコマンドを送らないこと(C610の初期化待ち)。
- Bluetoothペアリング: DualSenseは PS + Create ボタン長押しで青点滅、この間にESP32側でスキャン開始。

### CAN制御プロトコル (参考)

- 送信ID: 0x200 (ID 0x201-0x204 の4台分まとめて制御)
- データ長: 8バイト
- バイト構成: [ID1_H, ID1_L, ID2_H, ID2_L, ID3_H, ID3_L, ID4_H, ID4_L]
- 各16bit値: 電流指令 (-10000 〜 +10000 を -10A 〜 +10A にマップ)
- 送信周期: 1 kHz (1 ms 毎) 推奨
- 受信ID: 0x201, 0x202 から角度/速度/電流/温度のフィードバック

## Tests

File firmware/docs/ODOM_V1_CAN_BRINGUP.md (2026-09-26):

# V1 ODOM CAN単体試験

対象: STM32F405RGT6 + TCAN1051VDRQ1。V2設計と独立した実装確認。
`can_f405.hex`はAMT102/IMU処理を含まない。通常制御ファームではない。

## 接続

V1製造PCB `hardware/odometry-board/Oddom board/Oddom board.kicad_pcb`を照合:

- J2 pin1=CAN H、pin2=CAN L、pin3=GND。USB-CAN H/L/GNDへ接続。
- U4 pin1=TXD→PA12、pin4=RXD→PA11、pin3=5V、pin5=3.3V、pin8=S→GND。
- SWDはJ8。J7はIMU用でありデバッグ用ではない。
- バス両端だけ120Ω。無給電でH-L間約60Ωを確認する。
- F405側はClassic CAN 1Mbps、標準11bit ID。CAN FDは使わない。

USB-CAN実測: VID=1D50/PID=606F、serial=`003800394633500E20303035`、
USB名=`canable2 gs_usb`。ユーザー申告型番はSH-C31A。
BOOT OFFで接続する。WindowsではCAN Interface 0にWinUSBが必要。
ST-LinkやUSB Composite Deviceのドライバを変更しない。

## 診断ファーム

`scripts/build.ps1`で`build/debug/can_f405.hex`を生成。
既存`flash.ps1`はG474本体専用なので本ターゲットには使わない。
F405 Device ID=0x413とプローブSNを確認し、必要ならsector0を退避した上で
CubeProgrammerに明示的に本HEXを渡してwrite/verify/resetする。

起動時にHSI16MHzのsilent loopbackでID/DLC/8byte一致を確認。
次にHSE8MHzへ切替え、APB1=8MHz、BRP=1、BS1=5、BS2=2、SJW=1、
sample point=75%で通常通信。水晶起動失敗時は停止し、HSIへ代替しない。
NARTで送信1回のみ、ABOMでbus-off自動復帰。RUNは1Hz、COMMは受信時、
ERRは初期化例外またはCAN warning/passive/bus-off時に点灯。

以下は独立ベンチ専用ID。製品プロトコルへの追加ではない。

| ID | 方向 | 内容 |
|---|---|---|
| 0x6E4 | PC→F405 | DLC 0〜8のテストデータ |
| 0x6E5 | F405→PC | 上記受信データをそのまま返す |
| 0x6E6 | F405→PC | 1Hz、uint32 uptime ms + uint32 RX数、little endian |

`scripts/read-can-f405.ps1`でSWD Hot Plug読取。SRAM先頭のmagicはF405CA01。
phase=3/fault=0/loopbackOK=1/hseReady=1が初期化成功。
fault: 1=CAN init待ち、2=init解除待ち、3=loopback受信待ち、
4=loopback内容不一致、5=HSE待ち、6=clock切替待ち。
各値はlive読取であり同時snapshotではない。

## PC試験

Python環境を`build/can-host`に作成済み。
依存: python-can 4.6.1、gs-usb 0.3.1、libusb-package 1.0.30.0。

```powershell
.\firmware\build\can-host\Scripts\python.exe firmware/scripts/test-can-f405.py --count 10
.\firmware\scripts\read-can-f405.ps1
```

USB自身の送信echoは成功に数えず、0x6E5のsequenceを含む全8byte一致を評価。
10/10応答、heartbeat受信、error frameなし、F405のtxOK/rx増加と
エラーカウンタを確認する。内部loopback成功だけで外部CAN合格とはしない。

## 2026-09-23現在

- 1608byte版をF405へwrite/verify/reset済み。内部loopback/HSE/通常モード移行成功。
- 初版はGPIO AF設定前のloopback初期化解除で停止。AF9/RX pull-upを
  初回init前に設定し修正、実機で成功を確認した。
- 外部txOK=0/rx=0。USB-CAN Interface 0がCode28でWinUSB導入待ち。
  TEC上昇/LEC=5を観測。対向機が使える状態になってから配線・終端も含め再評価。
- 元AMT102のsector0退避: `build/debug/f405-sector0-before-can-20260923.bin`。

### WinUSB導入後

- CAN Interface 0のCode28解消、USB control/bulk操作可能。
- 10回送信要求: 一致返信0、heartbeat受信0。F405側もtxOK=0/rxCount=0。
  外部CANは未成立。LEC=5 (bit dominant error)、TEC増加を観測。
- USB報告CAN clock=170MHz。PC計算値はBRP10/TSEG1=12/TSEG2=4、
  正確に1Mbps、sample point=76.47%。USB側one-shot非対応のため通常再送となる。
- USB側loopbackを一時起動し、固有payloadの送信echoが返ることを確認後stop。
  USB経路の確認でありF405からの返信ではない。外部CAN成功には数えない。
- V1基板終端はR1=120RとSW1。次は両端終端とJ2 H/L/GNDの現物照合。

### 受信経路の切分け

- ユーザー実測: H/L各2.45V、H-L67Ω、U4 pin3/5/8の電圧は正常との回答。
- 1752byte診断版へ更新。起動時、CAN reset後・HSE8MHz状態でPA12を
  一時GPIO出力へ切替え、短いHigh→Low→Highを出しPA11を読む。
  RX弱pulldownの読取後はpull-up/AF9へ戻す。独立ベンチ専用。
- SRAM word24..27の実測=BF0C/EF0C/FF0C/F70C。
  PA12は1→0→1、PA11は1→1→1、RX弱pulldownで0。
- 推定: PA11がU4 RXDの正常なpush-pull出力で駆動されていない可能性が高い。
  MCU内部pullによる変化はCAN受信成功ではない。
- 次: 無給電でU4実リード4(RXD)↔U1実リード44(PA11)の導通、
  U4実リード1(TXD)↔U1実リード45(PA12)の導通。
  導通良好なら給電時U4実リード4の電圧と実装方向/型番を確認する。
  この試験だけでははんだ/断線/IC損傷を区別できない。

参照: [ST CMSIS F405 register definitions](https://github.com/STMicroelectronics/cmsis-device-f4/blob/master/Include/stm32f405xx.h)、
[CANable接続ガイド](https://canable.io/getting-started.html)。

### 外部CAN最小試験合格（2026-09-23）

給電復帰後、10回の8byte echo全一致、heartbeat10件、PC error frame0。
F405のtxOKは0→20、rxCountは0→10、txFailは9→9（試験中増加なし）、
LEC=0/REC=0、FIFO overrun/echo drop=0。試験前ACK待ちで蓄積したTECは72→52。
USB自身のechoは判定から除外。双方向Classic CAN 1Mbpsの最小確認は合格。
具体的な現物修正内容は未聴取、長時間・高負荷・再起動再現性は未評価。
現在はCAN診断版を保持し、USB-CANは試験終了でstop。
起動時pathRxAtLow=1という単発値は残るが通常通信は実測成功しており、
この起動snapshotだけで現時点のRX断線を判定しない。

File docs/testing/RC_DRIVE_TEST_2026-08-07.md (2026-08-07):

# ラジコン走行試験記録（2026-08-07）

## 結果

ユーザー実施のラジコン試験で、無線操作によって機体を走行動作させられることを確認した。操作入力から走行系までの統合経路が実機で成立した最初のマイルストーンとして記録する。

## この時点で確認できた範囲

- ラジコン操作を走行指令へ反映できる。
- 走行系を実機上で動作させられる。
- 単体・空走試験から接地状態の統合試験へ移行できる。

## 未記録・未判定

次の条件は定量logが残っていないため、今回の結果からは判定しない。

- 送信機・受信機の型番、入力方式、failsafe設定
- battery本数、試験開始／終了電圧、路面、搭載質量
- 走行速度、加減速率、走行時間、実施maneuver
- battery A/B電流、contactor後motor bus電圧、C620電流・温度
- 送信機断、通信断、CAN timeout、E-stop、Teensy reset時の停止動作
- 急制動時の回生電圧とenergy

したがって、今回の結果は「走行成立」であり、最高速、連続運転、回生、通信断またはE-stopの受入試験完了を意味しない。

## 次回の試験順序

1. 車輪周囲を隔離し、E-stop担当者を置いて低速から開始する。
2. 前後、左右、その場旋回、斜行、並進＋旋回を各正逆で実施する。
3. 通常停止、送信機停止、指令通信断、unit CAN timeout、E-stop、電源再投入を個別に確認する。
4. battery A/B電圧・電流、`MOTOR_PWR_SENSE`、各C620のrpm/current/temperature、指令値、contactor状態を同一時系列へ保存する。
5. 25%、50%、75%のように段階的に速度を上げ、各段階で停止時を含む最大電流、最低battery電圧、最大motor bus電圧、温度、CAN errorを確認する。
6. 回生logからbrake resistorの抵抗値・pulse energyとchopperの作動閾値を選定する。

高速からの急制動は、contactor後motor bus電圧を観測できる状態にしてから実施する。

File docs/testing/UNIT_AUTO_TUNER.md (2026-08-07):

# 単一ユニット自動パラメータ探索

`tools/linux/unit_auto_tuner.py`は、単一差動ステアユニットの実機応答を
粗い探索幅から細かい探索幅へ自動収束させるベンチツールである。
Web UIの安全な目標プロファイル/STOPを使用し、ファームの`SET_CONFIG`は
SocketCANから直接更新する。

探索中は`SET_CONFIG idx22=5ms`でSTATUS1/2を200Hz送信し、Web UIがCAN上のfreshな
角度/wheel/steer rpmを受けて採点する。完了はG474のSTATUS3 `MOTION_SETTLED`を正本とし、
新指令後に一度Lowを観測してからのHighだけを採用する。各サンプルにはWeb UI側sequenceを付け、
同じsnapshotを複数回数えない。探索終了時はidx22=0で通常20/50ms周期へ戻す。
VCPが接続されている場合は、相補observerの推定角、推定軸rpm、AMT innovationも
`samples.csv`へ保存する。observer補正時定数は`steer_observer_tau_s`(`SET_CONFIG idx23`、
既定0.050s)、friction FF減衰速度は`steer_friction_ff_fade_axis_rpm`
(`SET_CONFIG idx24`、既定10rpm)として単独探索できる。observer角/innovation自体は
試行スコアや制御判定には使わない。
Web UIはClassic CAN移行ベンチ用`SET_TARGET_ACCEL_FF`も200Hz送信する。`samples.csv`の
`steer_accel_explicit_active`が1なら、G474は受信周期から再微分した加速度ではなく明示profile
加速度をFF/制動phaseへ使用中である。高速試験ではこの列が運動区間を通じて1であることを確認する。
制動Kp倍率はglobal `steer_brake_kp_multiplier`に加え、100/150rpm knotを
`steer_brake_kp_multiplier_100/150`で個別探索できる。global値を先に送り、個別knotを後から
上書きするため、低速倍率を保ったまま高速制動だけを強められる。

## 目的

手動の「1点試験→ログ確認→次の値を入力」を廃止し、次を同じ条件で比較する。

- 指定角度への0.5deg収束時間
- 運動学的な最短時間に対する応答倍率
- オーバーシュート、追従誤差、終端誤差
- wheel rpm維持誤差
- 指令/実測モータ電流ピーク
- 温度、安全停止、未収束数
- 正逆、wheel停止/回転中、絶対角度依存のばらつき

## 応答倍率

wheel rpmから10%予備付き差動モータrpm包絡線で許される最大steer速度を`V`、
移動角を`D`、加速/制動を`a,d`とする。`Dc=V^2/(2a)+V^2/(2d)`に対し、
非対称台形/三角形の基準軌道最短時間を使う。

```text
if D >= Dc:
    t_min = V/a + (D-Dc)/V + V/d
else:
    Vp = sqrt(2D/(1/a+1/d))
    t_min = Vp/a + Vp/d
response_ratio = measured_settle_time / t_min
```

値は1に近いほどよい。未収束、安全停止、終端誤差、オーバーシュートには
スコア上のペナルティを加え、単に目標プロファイルだけが速い候補を選ばない。
ゲイン性能試験は`--trajectory-time-scale 1`、本番受入は`2`とする。性能期限は最低でも
`2*t_min`を確保し、本番受入では`2*t_min+0.35s`を初期監視期限とする。0.35sは空走実測値で、
接地後の残差p99から更新する。期限超過後も`--trial-timeout`までは診断ログを継続する。

## 探索方式

各ラウンドで中心点と、各パラメータを現在幅だけ正負へ振った点を評価する。
最良点を次の中心にし、既定では幅を0.5倍にして繰り返す(pattern search)。
全組合せgridより実機試行数を抑えながら、粗→細探索ができる。

候補ごとに通常は次を実行する。

```text
enable
  -> wheel=0, +90deg
  -> wheel=target, -90deg
  -> ramp STOP -> disable
```

`--full-scenarios`ではwheel=0/targetの各正逆、計4移動を行う。
`--repeats N`では一式を反復し、平均と最悪値の両方で採点する。

## 推奨校正順序

カスケードの全パラメータを最初から同時探索すると、内周の遅れを外周ゲインで隠す候補も
同点になり、負荷が変わったときに崩れやすい。校正パッケージは次の段階に分ける。

1. 外周を切った速度step/PRBSでステア速度プラントを同定し、内周PIと速度フィルタを決める。
2. 内周値を固定して、外周angle Pとdeadbandを決める。生の角度DはAMT22量子化を増幅するため
   使わず、必要な減衰は実測mode速度を用いる。
3. 加速度FF、最大速度、加速/制動を別々にした中央プロファイルを決める。
4. wheel停止/回転、正逆、絶対角度、接地荷重、床材のシナリオ行列で回帰する。
5. 空走値を共通初期値とし、接地時は小さい探索幅だけ再実行する。

床材ごとの別ゲインを最初から持つのではなく、まず全条件で安全な共通ゲインを選び、摩擦FF・
負荷推定で差を吸収する。それでも帯域差が大きい場合だけ、測定可能な負荷状態に基づく
ゲインスケジューリングへ進む。

## ステアmode速度ループ単体同定

`tools/linux/unit_steer_mode_id.py`は、上記手順1のための専用ツールである。
通常の角度追従試験と異なり、試験中だけhold/moving angle Kpを両方0にし、
`SET_TARGET_FF`を直接ステア軸速度目標として使用する。加速/制動FFと摩擦FFも0にするため、
観測対象は速度LPF+steer mode PI+機構だけになる。

観測は既存`STATUS2 (0x190+unitId)`のmotor 1/2 rotor rpmを使用する。UARTを高頻度化すると
115200baudのポーリング送信が1kHz制御を止めるため、`SET_CONFIG idx22`で試験中だけ
STATUS1/2周期を1〜100msに設定する。0で通常周期(20/50ms)へ戻る。

現行Flash値`Kp=120, Ki=50, tau=2ms`の正負step:

```bash
python3 tools/linux/unit_steer_mode_id.py \
  --yes-wheel-lifted --pattern step \
  --kp 120 --ki 50 --filter-tau-s 0.002 \
  --amplitude-rpm 20
```

PRBS入力を保存する例:

```bash
python3 tools/linux/unit_steer_mode_id.py \
  --yes-wheel-lifted --pattern prbs \
  --kp 120 --ki 50 --filter-tau-s 0.002 \
  --amplitude-rpm 20 --chip-s 0.025
```

`amplitude-rpm`はステア軸rpmで、20rpm=120deg/s。stepは正負パルスとゼロ区間を組にし、
PRBSは31chip列とその反転を連結して角度ドリフトを抑える。結果は
`firmware/logs/steer-mode-id/<UTC timestamp>/samples.csv`と`metadata.json`へ保存する。
終了・例外・Ctrl-Cのいずれでもdisableを送り、変更したRAMパラメータを空走採用値へ戻す。
試験中にWeb UIが同じCANへ目標を再送すると角度目標が競合するため、mode IDはWeb UIが
応答中なら実行を拒否する。`unit_web_ui.py`を終了してから実行すること。開始角はbuffer済みVCP
文字列でなくfreshなCAN STATUS1から取り、STATUS3 ACTIVE確認後だけ計測する。外周angle Kp=0中の
安全用SET_TARGETはSTATUS1実角へ追従させ、速度指令は`steer-accel-rpm-s`でrampする。これにより
内周速度追従遅れを120deg angle-divergence異常と誤判定せず、ACTIVE脱落時は即時中止・復帰する。

比較はまずKi=0でKp/tauの安定限界と立上りを決め、次にKiを足して定常偏差を消す順で行う。
LPFを短くすると位相遅れは減るがC620 rpm量子化と機構ノイズが増えるため、立上りだけでなく
正負のovershoot、tail MAE、再現性を同時に確認する。

## 実行例

前提として、wheelを浮かせてWeb UIを起動する。

```bash
python3 tools/linux/unit_web_ui.py --vcp-port /dev/ttyACM0
```

Kp、Ki、中央steer速度/加速度を3ラウンド探索する例:

```bash
python3 tools/linux/unit_auto_tuner.py \
  --yes-wheel-lifted --apply-best --full-scenarios \
  --params steer_kp,steer_ki,steer_rate_dps,steer_accel_dps2 \
  --center steer_kp=80 --center steer_ki=25 \
  --center steer_rate_dps=240 --center steer_accel_dps2=3600 \
  --span steer_kp=40 --span steer_ki=20 \
  --span steer_rate_dps=60 --span steer_accel_dps2=360 \
  --rounds 3 --trial-timeout 3
```

特定の値を固定して1変数を反復比較する例:

```bash
python3 tools/linux/unit_auto_tuner.py \
  --yes-wheel-lifted --full-scenarios --repeats 2 \
  --params steer_decel_dps2 \
  --fixed steer_kp=80 --fixed steer_ki=25 --fixed steer_rate_dps=240 \
  --fixed steer_accel_dps2=3600 \
  --center steer_decel_dps2=2250 --span steer_decel_dps2=150 \
  --rounds 1
```

候補別の連続バッチによる時間順・絶対角バイアスを避けるため、1変数の明示候補を
インターリーブ比較する例:

```bash
python3 tools/linux/unit_auto_tuner.py \
  --yes-wheel-lifted \
  --params steer_backcalc_gain --compare-values 0,1,2 \
  --repeats 2 --wheel-rpm 265 \
  --fixed steer_kp=160 --fixed steer_ki=50 \
  --fixed steer_max_rpm=150 \
  --fixed steer_accel_limit_rpm_per_s=2000 \
  --fixed steer_rate_dps=900 \
  --fixed steer_accel_dps2=12000 \
  --fixed steer_decel_dps2=5400
```

`--compare-values`は`--params`を1変数に限定する。各wheel条件で毎移動の方向を交互にし、
全候補へ正逆を1回ずつ割り当てて元の絶対角へ戻る。偶数repeatでは最初の方向を反転し、
反対側の絶対角帯も全候補へ均等に割り当てる。各試行後は通常STOP/Disableし、PI積分と
observer状態をリセットしてから次候補を適用する。

Flash後の中心点だけを回帰確認する例:

```bash
python3 tools/linux/unit_auto_tuner.py \
  --yes-wheel-lifted --evaluate-only --full-scenarios \
  --params steer_decel_dps2 --center steer_decel_dps2=2250 \
  --repeats 3
```

`--evaluate-only`は常に1 roundだけ実行する。反復数は`--repeats`で指定し、既定rounds=3による
同一中心点の意図しない3重実行は行わない。高速試験では`steer_commissioning_cap_rpm`を
`--fixed`で指定でき、Web UI capを先に更新してからrateを設定する。100/150rpm個別knotは
`steer_kp_100`等の`Kp/Ki/accel_ff/decel_ff/backcalc`パラメータとして探索できる。

## 出力

`firmware/logs/auto-tune/<UTC timestamp>/`へ逐次保存する。

- `trials.csv`: 各移動の生評価値
- `summary.csv`: 候補別スコア、平均/最悪収束、失敗数
- `score.svg`: 各パラメータ値とスコアのグラフ(外部plot依存なし)
- `metadata.json`: 引数、開始幅、最良値、最終適用値

応答の速さと振り返しを分離するため、`trials.csv`には次も保存する。

- `first_entry_2deg_s`: 初めて目標±2deg境界へ到達した時刻(隣接sample間を線形補間)
- `first_entry_band_s`: 初めてsettle band(既定±0.5deg)境界へ到達した時刻(同補間)
- `first_crossing_s`: 初めて目標角を通過した時刻(同補間)
- `resettle_after_entry_2deg_s`: 初回±2deg進入からSTATUS3 settledまでの時間

高速域では100Hz sample間に数deg進むため、帯内sampleの有無だけでは初回通過を取り逃し、
overshoot後の再進入を初回到達と誤判定する。上記3時刻は移動方向に沿った誤差境界の最初の
crossingを線形補間し、sample rateに起因する合否反転を避ける。

インターリーブ比較の空走・応答優先ゲートは、全試行で安全停止なし、`first_entry_2deg_s` 0.50s以下、
overshoot 20deg以下、終端誤差1deg以下。合格候補から平均`first_entry_2deg_s`が短い値を選ぶ。
旧overshoot 4deg/settle 0.9s gateは`strict_settle_failures/pass`へ診断値として残す。
20degはunit 1浮上状態で300rpm commissioningを進めるための一時基準で、接地3輪へは流用しない。

P0高速telemetry実装後は、`samples.csv`へschedule rpm、scheduled Kp/Ki/加速・制動FF、
共通scale前後のsteer電流、残差、連続飽和ms、scale/制動phaseも保存する。`trials.csv`には
実steer peak rpm、reference減速開始、実速度peakで定義した実減速開始、その時間差、
scale総時間/最長連続時間を追加する。正負は既存`direction`列で分離できる。
`steer_backcalc_gain`/`drive_backcalc_gain`は`SET_CONFIG idx25/26`として0〜20/sを探索でき、
各周期のsteer/drive積分補正量も`samples.csv`へ保存する。

プロセス中断、例外、温度上限、ファーム安全停止時も通常はWeb UIの減速STOPを
試みる。Web APIが失われた場合だけ直接disableへフォールバックする。
EnableはCANへ2回送信し、STATUS3 `ACTIVE`を0.5s以内に確認してから最初の目標を送る。
確認できない場合はdisableして候補を失敗扱いにし、未Enable状態のログを性能値へ混ぜない。

高速試験用の入力範囲はsteer rate 2046deg/s、profile accel/decel 12000deg/s2までとする。
いずれもunit側の差動mode hard包絡を解除する値ではない。`steer_accel_limit_rpm_per_s`
(`SET_CONFIG idx9`, 100〜4000rpm/s)を候補に含める場合、試験終了時は開始時runtime値へ戻す。
idx9は通常の軌道生成器ではなくユニット側の最終ガードであり、中央が送る最大加速度より
十分高く設定して二重ランプを避ける。boot既定値600rpm/sは安全な単体起動用として維持する。

## 空走値と接地値

空走探索で確定できるのは、センサ/通信遅延、差動干渉、無負荷安定限界、
目標プロファイル追従帯域である。接地時はタイヤ静止摩擦、横力、荷重移動、
3輪拘束が加わるため、空走最良値を中心に狭い幅で再探索する。

接地探索では温度・電流余裕に加え、低速stick-slip率、車体姿勢誤差、
3輪間の飽和/拘束をスコアへ追加して最終値を決める。

## 2026-07-31 空走採用値

- 局所制御: steer mode `Kp=120`, `Ki=50`, hold angle `Kp=4`, moving angle `Kp=1`,
  deadband `0.3deg`, mode速度LPF `tau=2ms`, 加速/制動FF gain `0.5/0.5`,
  wheel依存テーパ付き摩擦FF `200raw`（30rpmで0、80〜235degは最大2倍）
- 中央プロファイル: 最大`360deg/s`（60軸rpm commissioning段階）、加速`3600deg/s^2`,
  制動`2250deg/s^2`, 生成`200Hz`
- time scale=2の本番受入はwheel 0/265rpm、正逆90deg、12試行でCAN収束12/12、
  deadline `1.273s`以内12/12、平均`1.146s`、最悪`1.250s`、最大overshoot`1.054deg`。
- current limitは`4000 raw`。3000/4000/5000/6000比較では電流クランプが律速でなかった。
- 初期試験でWeb側だけを300/360deg/sへ上げた際は、ユニット側`steer_max_rpm=40`が残って
  いたため240deg/sより遅かった。角度依存stall対策後、ユニット側上限も60rpmへ同時に
  上げた再試験はwheel=0/265rpm・複数絶対角で26/26合格し、60rpm段階を採用した。
  steer minimum rpmと全wheel rpmへ一律に加えるCoulomb摩擦FFは未収束を増やしたため不採用。
  2026-07-31に
  wheel=0近傍だけへテーパ適用する200rawと角度依存ブーストを採用し、time scale=1.0を
  既定化した。接地後は空走値を中心に狭い範囲で再探索し、複数バッチのworst/failed数を
  必ず確認する。

## 2026-07-31 高速域の方針

60〜156rpmの空走試験により、100rpm超は固定PI/固定FFのまま電流上限だけを増やす方針を
採らない。実速度は156rpmまで到達したが、120〜150rpm帯では減速後の速度残りによって
overshootが10〜15degへ増えた。4000raw未満でも同現象が出たため、一次原因は電流不足ではない。

今後は`docs/control/HIGH_SPEED_STEER_GAIN_SCHEDULING_PLAN.md`に従い、telemetryと
back-calculation anti-windupを先行実装した後、0/60/100/150rpmの速度帯で連続補間する。
current limitは加速中の不足が計測で確認された場合だけ段階的に上げる。

同日P4ではauto tunerの再現可能な既定値を120rpm packageへ更新し、`steer_max/cap=120rpm`、
unit hard guard=2000rpm/s、profile=720/5400/2000deg系、100/150 knot Kp/Ki=140/50、
decel FF=2.5、brake Kp倍率2を使う。300rpm段は必ず`--fixed`でmax/cap/rate/accel/decelを明示する。
300rpm capの90deg試験は6/6実用合格した。当初の連続実速度確認はmode IDの260rpmまでだった。

同日の復旧後試験で300rpm実速度へ到達したが、`unit_steer_mode_id.py`旧版の対称4000rpm/s
rampによる300→0急制動で電源保護停止が発生した。改修版は`--steer-decel-rpm-s`既定500rpm/s、
制動所要時間+zero dwell、0rpm経由の反転、zero確認後Disableを使う。最初の再確認は
`--step-direction positive`の単方向1 pulseで実施し、peak 300.9rpm、0.595s制動、feedback維持で
完走した。4000rpm/s制動は再使用せず、追加反復前に24V bus peakを計測する。

## 24V回生計測ゲート

現ベンチの`STATUS3.busVoltageMv`は未実装値`0xffff`で、G474基板のADCは5V制御電源監視専用。
C620のCAN feedbackも角度・速度・トルク電流・温度だけで24V入力値を含まない。このため
260 axis rpmを超える`unit_steer_mode_id.py`試験は、外部24V計測なしでは
`--steer-decel-rpm-s <= 500`を強制する。外部計測器を接続し`--yes-24v-monitored`を明示した
場合だけ、500rpm/sを超える制動試験を許可する。

計測はC620へ入る24V/GND間を、single-shotオシロまたは十分な過渡捕捉能力を持つmin/max計で
観測する。接地型オシロを使う場合は、電源負極・保護接地との関係を確認し、接地クリップで
短絡を作らない。必要なら定格の合う差動プローブまたは絶縁された計測器を使う。

最初の計測条件はwheel浮上、単方向1 pulse、300rpm、pulse 0.3s、加速4000rpm/s、制動500rpm/s:

```bash
python3 tools/linux/unit_steer_mode_id.py \
  --yes-wheel-lifted --yes-24v-monitored \
  --pattern step --step-direction positive \
  --amplitude-rpm 300 --pulse-s 0.30 --zero-s 0.25 \
  --steer-accel-rpm-s 4000 --steer-decel-rpm-s 500
```

初期電圧、制動中peak、電源型番・OVP設定/表示、C620 LED、feedback drop数を記録する。
DJI公式C620ガイドが明示するのはrated 24Vで、最大連続入力電圧は記載されていないため、
推測したC620上限を合否値にしない。使用電源のOVP仕様とC620の追加一次資料が揃うまでは、
「電源が落ちなかった」だけで減速率を500rpm/sより上げない。

計測器導入前のランプ吸収評価では、負方向300rpmもpeak300.9rpm、feedback drop 0で完走した。
位置profileも制動3000deg/s2(500 axis rpm/s)へ制限した。応答優先の空走候補は
cap300rpm、加速12000deg/s2、制動3000deg/s2、current limit4500raw。4000/4500rawを170degで
各4移動インターリーブし、4500はfirst-entry平均0.344s、overshoot最大16.152degで4/4実用合格。
90deg full 4移動もfirst-entry最悪0.243s、overshoot最大15.205degで4/4合格した。
試験後はcurrent limit4000raw、GUI cap60rpmへ戻し、boot既定は変更しない。

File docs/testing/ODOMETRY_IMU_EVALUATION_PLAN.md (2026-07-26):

# オドメトリ+IMUモジュール評価計画

作成: 2026-07-26(状態: 方針確定、治具製作・計測は未着手)

## 目的

オドメトリ基板(3輪AMT102 + ICM-42688-P、unitId=4)が算出するpose(x/y/θ)の精度を検証する。`electrical/ODOMETRY_BOARD_REQUIREMENTS.md`で定義済みの配信仕様(pose 100Hz、健全性10Hz)を前提に、その数値の妥当性の裏付けと、センサフュージョンの重み付け方針を確定する。

## ホイール構成

AMT102 x3のうち2輪は平行配置、1輪は独立(直交方向)配置。平行2輪ペアは「平均=前進」「差分/トレッド幅=回頭」という計算になっており、独立1輪が横方向変位を担う想定。

## 評価の2段階(2次元経路治具は不採用)

XY全体をトレースする2次元経路治具は製作難度が高いため不採用とした。代わりに、系統誤差(スケール・トレッド幅)を切り分けて評価する2つの単純な治具で代替する。曲線走行中の過渡的な誤差までは評価対象外とする。

| 試験 | 治具 | 検証する誤差 |
|---|---|---|
| 直線スライダー試験 | 定規+スライダー。各輪を既知距離だけ独立に往復させる | 各輪の線形換算精度(カウント数→距離のスケール誤差) |
| 回頭ピボット試験 | 固定ピボット+角度ゲージ(または旋回台)。既知角度だけ基板ごと回転させる | 平行2輪の差分計算に使うトレッド幅の校正誤差 |

直線試験だけでは回頭誤差は原理的に検出できない。平行2輪は直線移動中は常に同じだけ動くため差分が常時ゼロになり、差分計算に使うトレッド幅の設定値が間違っていても誤差が表に出ない。2試験を組み合わせて初めて、静的な系統誤差(スケール・トレッド幅)をカバーできる。

## IMUセンサフュージョンの重み付け方針

「勘で重みを決める」のではなく、各センサの誤差特性を先に測ってから重みを導出する方針とする。

- **ジャイロ(ICM-42688-P)ドリフト特性**: 静止状態でジャイロを積分し続け、時間あたりのθドリフト量を測定する。データシートのnoise densityとも突き合わせる
- **ホイールオドメトリのθ誤差特性**: 上記の回頭ピボット試験で、特にスリップが出やすい条件(高速回頭、路面条件)を振って誤差の出方を測る

両者の誤差特性(分散)が分かれば、相補フィルタの時定数やカルマンフィルタのR行列は計算で決まり、手動チューニングの範囲を最小化できる。

## 更新周波数の考え方

「精度」を2つに分けて考える。

1. **推定値そのものの精度**: 内部の積算(エンコーダカウント・ジャイロサンプリング)レートで決まる。デッドレコニングは微小変位の積分処理なので、サンプル間隔が粗いと並進+回頭が同時に起きる場面で円弧を直線近似する誤差が乗る。ここは既にTIM Encoder Modeで固定周期1kHzが仕様化済み(`ODOMETRY_BOARD_REQUIREMENTS.md`)であり、ハードウェアタイマ駆動でほぼコスト無しなので、これ以上の検討は不要
2. **消費側(Teensy)が使う値の鮮度**: central CANへの配信レートで決まる。消費側の車体逆運動学は100Hzで動く設計(`control/CENTRAL_COORDINATED_CONTROL.md`)なので、配信もこれに合わせるのが妥当。既存要件のpose 100Hz配信はこの理屈と整合している

ユニットMCUの1kHz制御ループはSET_TARGET追従用の別経路であり、オドメトリのデータを消費しないため、配信レートをそちらに合わせる理由はない。配信を100Hzより上げる場合も、Teensy自身が100Hzでしか制御判断を更新しないため、得られる効果は「Teensyが読みに行く瞬間の値の古さ」が最大10ms→数msに縮む程度の二次的なもので、優先度は低い。

## 実施順序

1. 直線スライダー試験(各輪独立、既知距離)
2. 回頭ピボット試験(既知角度)
3. ジャイロ静止ドリフト試験
4. 1〜3の結果からセンサフュージョンの重み(時定数/分散)を導出

## 関連ドキュメント

- `electrical/ODOMETRY_BOARD_REQUIREMENTS.md` — ハードウェア構成、配信仕様(pose 100Hz/健全性10Hz)、SPI IMU配線
- `control/CENTRAL_COORDINATED_CONTROL.md` — pose推定値を消費する中央Teensyの車体逆運動学(100Hz)
- `testing/SINGLE_MODULE_LOAD_EVALUATION_PLAN.md` — 同時期に策定した差動ステアユニット単体の評価計画(姉妹文書)

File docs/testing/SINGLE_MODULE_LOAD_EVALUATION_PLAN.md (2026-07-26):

# 単一モジュール評価計画(負荷ロバスト性検証)

作成: 2026-07-26(状態: 方針確定、治具製作・計測は未着手)

## 目的

差動ステアユニット1基について、ステア収束速度・ホイールrpm挙動が理論値に近く、かつ負荷変動でロバスト(挙動が変化しない)であることを検証する。ここで確立した制御・評価手法を土台に、`control/CENTRAL_COORDINATED_CONTROL.md`の3輪協調(高レイヤーからのwr/ws配信)と`control/LOAD_ADAPTIVE_CONTROL_ROADMAP.md`の負荷適応制御へ接続する。

## なぜモジュール単体評価が難しいか

差動ステアは1モータの出力がwheel/steer両方に同時に効く(`DRIVE_RATIO=32/11`, `STEER_RATIO=8/11`)ため、独立スイーブモジュールと異なり「steerだけ」を機構的に切り離して評価できない。負荷試験・評価軸はこの前提で設計する。

## 治具方針

検討した3案と採否:

| 案 | 採否 | 理由 |
|---|---|---|
| 実機3モジュール同時稼働 | 不採用 | 3輪相互干渉で異常原因を切り分けられない。独立評価にならない |
| 単輪+台車+重り | 不採用 | 荷重印加が不安定で治具として成立しにくい |
| **4隅従動輪+中央に評価対象モジュール1基** | **採用** | 荷重がシャーシ経由で接地点に伝わり実機に近い。駆動は1モジュールのみで独立評価を維持でき、重り位置で荷重段階も作れる |

5点接地(駆動1+従動4)は静定性に懸念があるため、従動輪側に多少のコンプライアンス(バネ等)を持たせて全点接地を保証する。重り自体は水・米袋等、精密な分銅である必要はない。

## 動作包絡線(理論値・マージン)

モータ定格469rpm(M3508+C620出力軸)、`n_drive = 2.909×(n1-n2)/2`, `n_steer = 0.727×(n1+n2)/2` から、2モータの共有電流予算による結合包絡線を導出する(`|n1|,|n2| ≤ 469`の正方形制約領域が、差動の線形変換で菱形に写る)。

理論境界:

$$
\frac{|n_{drive}|}{1364} + \frac{|n_{steer}|}{341.1} \le 1
$$

マージン10%を適用した目標境界(係数を0.9倍):

$$
\frac{|n_{drive}|}{1228} + \frac{|n_{steer}|}{307.0} \le 1
$$

| 動作パターン | 理論値 | 目標値(90%) | 備考 |
|---|---|---|---|
| 純駆動(steer=0) | 1364 rpm | 1228 rpm | 実測1200rpm(2026-07-07 wheel定常試験, p-p 3.5〜4rpm)とほぼ一致。マージンの妥当性を裏付け |
| 純操舵(drive=0) | 341.1 rpm (2047°/s) | 307.0 rpm (1842°/s) | 現行ソフト上限`steer_max_rpm`=40rpm(240°/s)は理論比12%・目標比13%で大幅に余裕あり |
| 片側モータのみ(n1=469, n2=0) | 682 rpm / 170.5 rpm (1023°/s) | 614 rpm / 153.4 rpm (921°/s) | 理論境界上に乗る参照点。`control/KINEMATICS_AND_RPM.md`の数値例と一致 |
| wheel運用下限 | 75 rpm | — | 40rpmはstick-slipで不可と実測済み(2026-07-07) |

**steer軸の実運用目標は理論マージンでなく競技要求から決める。** 理論値に対してすでに桁違いの余裕があり、包絡線側が制約になる状況ではないため。

## 制御ループ周期(実装済み・追加作業不要)

ユニットMCU側は`CONTROL_PERIOD_MS=1`(`firmware/src/main.c`)で1kHz制御ループが既に実装済み。これはC620自体のCANプロトコルが1kHz固定(指令送信・フィードバック受信とも)であることに整合しており、これ以上ユニット側ループを速くしても実効更新レートは伸びない。C620内部の(非公開・高速な)電流ループ + ユニットMCUの1kHz速度/位置ループ、というカスケード構成がすでに成立している。**残る改善余地はデジタルループ速度ではなく機構帯域(バックラッシュ・摩擦)側にある。**

## 計測項目

### 0. wheel rpm計算値の信頼性確認(最初に実施)

steer固定(純駆動、n1≈-n2)の条件で、モータエンコーダ由来のwheel rpm計算値(`feedback.rpm / 19 × DRIVE_RATIO`)が実際の出力軸rpmと一致するかを検証する。無負荷・負荷双方で実施。

- 問題なければ、以降はモータエンコーダ由来の値を信頼して進める(外部計装は不要)
- 問題があれば、出力軸に外部エンコーダ(`AMT102`仮設。オドメトリ基板採用品と同型・同ファームパターン=TIM Encoder Modeを流用)を追加する

この確認はsteer固定・純駆動条件でのみ妥当性を保証する。steer同時動作時のバックラッシュ挙動までは保証しない点に注意。

### 1. 負荷試験本体で記録する状態量

- wheel rpm(モータエンコーダ由来、0で信頼性確認済みのもの)
- steer角度(AMT222、出力側直結のため既に信頼できる)

### 2. 電気量

- `torque_current`(C620フィードバック。`c620.c`でデコード済みだが現状`main.c`のログには出力していない。追加が必要)
- `temperature_c`

負荷時に電流飽和で頭打ちになっていないか、ゲイン不足と切り分けるために必須。

### 3. 試験条件の振り方

- wheel目標rpm: 複数点(75 / 500 / 1200 rpm 等、既存ログの条件を踏襲)
- steer目標角度Δθ: 複数段階(小角度 〜 90° 〜 180°)
- 荷重レベル: 無 / 軽 / 重 の複数点(「変化なし」を主張するには最低2点比較が必要)

### 4. 評価する量

- 各条件の整定時間・オーバーシュート・定常p-p(wheel, steer双方)
- 片方をステップさせた際、もう片方に生じる乱れ量(クロスカップリング)
- 上記すべての**無負荷条件との差分**(絶対値でなく「負荷でどれだけ劣化したか」が本題)

## 実施順序

1. steer固定でのwheel rpm信頼性確認(無負荷・負荷)
2. 独立軸試験(無負荷) — 大部分実施済み(`PROGRESS.md`の2026-07-07試験群を参照)
3. 同時指令試験(無負荷、治具不要) — クロスカップリングデータ取得。既存NUCLEOベンチのまま、指令の出し方を増やすだけで着手できる
4. 4隅従動輪治具の製作
5. 負荷試験本体(2・3を負荷条件で再実施し、無負荷との差分を評価)

3は差動の合成数式そのものに起因する現象で負荷に依存しないため、4(治具製作、時間がかかる)を待たずに着手できる。

## 関連ドキュメント

- `control/KINEMATICS_AND_RPM.md` — ギア比・rpm・トルクの導出根拠、包絡線計算の元データ
- `control/CENTRAL_COORDINATED_CONTROL.md` — この評価で得る収束特性を使う高レイヤー側の3輪協調(車体逆運動学、wr/ws配信)
- `control/LOAD_ADAPTIVE_CONTROL_ROADMAP.md` — 負荷下で性能が崩れた場合の制御強化ロードマップ(FF・摩擦補償・DOB)
- `testing/NUCLEO_BENCH_TEST_PLAN.md` — ベンチ機材・段階テストの基礎手順

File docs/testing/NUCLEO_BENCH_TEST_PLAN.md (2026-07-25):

# CAN-G474 / CAN-L431ベンチテスト計画(通信・差動制御ループ実証)

## 目的

自作基板の発注前に、購入済みのMatek CAN-G474を主試験機として、2系統CAN、CAN物理層、配線、終端、1Mbps通信と差動ステアユニット1基の制御ループを検証する。CAN-L431は中央CANの対向ノードとして使う。NUCLEO-G474REは書込み復旧、自由なI/O、現行ファーム回帰確認用の予備とする。

CAN-G474はSTM32G474CE搭載でCAN 2系統のため、2バス同時動作を検証できる。ただし現行NUCLEO用ファームとはCAN2とAMT22 SPIのピンが異なる。ボード定義を分離し、CAN-G474用にCAN2=PB5/PB6、SPI2=PB13/PB14/PB15、AMT22_CS_N=PB12を設定してから使用する。

## 機材

| 機材 | 用途 |
|---|---|
| Matek CAN-G474 | 購入済み主試験機。G474、CAN 2系統、カスタムファーム、差動制御の検証 |
| Matek CAN-L431 | 購入済み対向ノード。CAN配線、極性、終端、1Mbps中央CAN通信の検証 |
| NUCLEO-G474RE | 予備。書込み復旧、現行ピン設定の回帰、CAN-G474で露出していないI/Oの検証 |
| MCP2551モジュール | C620 CANトランシーバ代用(ベンチ限定。本番はTCAN332) |
| AMT222A-V | ステア角検出 |
| 差動モジュール完成品(C620 x2 + M3508 x2) | 制御対象 |
| 24V電源(LiPoまたは安定化電源)+ ヒューズ + スイッチ | C620給電。手の届く位置に遮断手段 |

## MCP2551の3.3V接続(確認済み、DS20001667G)

| 項目 | 値 | 結論 |
|---|---|---|
| TXD VIH | min 2.0V | 3.3VのG474出力で直接駆動できる |
| RXD VOH | 0.7VDD≈3.5V以上 | **5VトレラントFTピンで受ける。** PB12はFT(ピン表のFT表記を念のため確認) |
| VDD | 5V | NUCLEOの5Vピンから給電 |
| RS(スロープ制御) | 1Mbpsでは**GNDへ落とす** | モジュールのRSが抵抗でプルアップされている場合はGNDにジャンパ |

本番基板はTCAN332(3.3V)なのでこの注意はベンチ限定。CANバス上の信号レベル自体は5V系/3.3V系トランシーバで互換なので混在は問題ない。

## 配線表

推奨ピン割当(CARRIER_BOARD_REQUIREMENTS.md)と同一。

| NUCLEO | 接続先 | 備考 |
|---|---|---|
| PB13 (FDCAN2_TX) | MCP2551 TXD | |
| PB12 (FDCAN2_RX) | MCP2551 RXD | FTピン |
| 5V | MCP2551 VDD、AMT22ピン1 | |
| GND | MCP2551 GND、AMT22ピン4、C620電源GND(共通GND必須) | |
| PC10 (SPI3_SCK) | AMT22ピン2 | 直結 |
| PC12 (SPI3_MOSI) | AMT22ピン3 | 直結 |
| PC11 (SPI3_MISO) | AMT22ピン5 | 直結(AMT22出力は3.3V) |
| PD2 (GPIO) | AMT22ピン6 CS | ソフト制御 |
| MCP2551 CANH/CANL | C620 x2 CAN | 短く。デイジーチェーン |

終端の確認: 無電源でCANH-CANL間の抵抗を実測する。約60Ω=120Ωが2個で正常。約120Ω=1個なので、モジュール側かバス端にもう1個追加(ベンチの短配線なら120Ω 1個でも大抵動くが、エラーカウンタを見ること)。

C620のID設定: SETボタンでモーター1=ID1、モーター2=ID2に設定し、モジュールに書いておく。

## 段階テスト

各段階で観測値(レジスタ、カウンタ、角度、rpm)をVCP(PA2/PA3、USBでそのまま見える)へprintfし、前の段階に戻れる形で進める。

0. **CAN-G474 bring-up**: 5V給電、SWDまたはUART1 DFU、Device ID、LED/GPIOによるカスタムファーム実行を確認する。CAN-G474用リンカ設定とピン定義を選択する。
1. **2系統FDCAN試験**: CAN-G474上でCAN1(PA11/PA12)とCAN2(PB5/PB6)を内部ループバック後、同時に通常モード・1Mbpsで動かす。CAN-L431を中央CANの対向ノード、C620をCAN2側として送受信・エラーカウンタを確認する。
2. **C620フィードバック受信**: モーター指令ゼロのまま、0x201/0x202の受信(角度・rpm・電流・温度)を確認。受信周期1kHzが安定しているか。
3. **開ループ微小電流**: ホイールを浮かせ、0x200へ微小電流指令(±1A以下)。両モーターの回転方向とフィードバック符号を対応付けて記録する。
4. **AMT22読み取り**: 0x00,0x00リード、チェックビット検証、2bit右シフト、ゼロ点オフセット適用。手でステアを回して角度が単調に追従するか。起動時200ms静止を守る。
5. **モーター速度ループ**: 各モーター個別のrpm PI制御。ステップ応答をログ。
6. **差動運動学の結合**: 2モーターの和/差からホイール速度・ステア速度へ変換し、AMT22によるステア角ループを閉じる。まずステア角ホールド(ホイール速度0)、次にステア角固定+ホイール回転、最後に同時。
7. **外乱・限界確認**: ステア最大速度、rpm上限制限、指令タイムアウト時の安全停止(SET_TARGET途絶→ゼロ指令)。

合格条件はBUILD_PLANフェーズ1と同じ: AMT22が読める / C620 x2に指令が出てフィードバックが返る / 低速でステアと駆動が独立に制御できる。

## 安全

- ホイールは常に接地させない(治具固定)。
- 電流指令に上限クリップをファームで入れてから初回通電する。
- 24Vはヒューズ経由、遮断スイッチを手元に。
- AMT22は電源投入時に静止させる。
- 初回は片方のC620だけ接続して1モーターから始めてよい。

## ファーム実装項目(このテストで書くもの)

- FDCANドライバ(1Mbps、フィルタ、送受信)
- C620プロトコル(0x200指令エンコード、0x201/0x202デコード)
- AMT22ドライバ(SPI3、バイト間2.5µs/リード間40µs、チェックビット、オフセット)
- モーターrpm PIループ、差動運動学、ステア角ループ
- VCP経由の簡易CLI/テレメトリ出力

これらは自作基板でもそのまま使う。ピンはPAx/PBx名で書き、`platform/`層に隔離する(firmware/AGENTS.md準拠)。

## 補足: オドメトリユニット

3輪オドメトリ(AMT102 x3、Z相なし4線VCC/GND/A/B)+専用STM32F405RGT6基板(`docs/electrical/ODOMETRY_BOARD_REQUIREMENTS.md`)。
G474 NUCLEOではタイマEncoder Modeと上位ロジックの先行試験だけを行えるが、F405固有のクロック、VCAPを含む電源、USART2、bxCAN、Flash sectorは検証できない。
最終ベンチ試験はF405オドメトリ基板またはF405評価ボードで、TIM2/TIM3/TIM4の手回しカウント、方向符号、1回転count数まで確認する。

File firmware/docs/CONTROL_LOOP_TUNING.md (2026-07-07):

# Differential control-loop tuning notes

最終更新: 2026-07-06(RoboMaster系オープン実装と比較し、積分独立クランプ等を導入)

## 目的

入力を「目標ホイールrpm」と「目標ステア角」とし、AMT222A-Vの絶対角およびC620 x2の
rpmフィードバックから、C620電流指令を生成する。

## 現在の制御構成(確定)

```
角度P(deadband付き) → 目標ステアrpm(min/maxクランプ+加速度制限)
  → モード座標PI x2(操舵=共通モード、駆動=差動モード、rpmは一次LPF後)
    → i1 = iSteer + iDrive, i2 = iSteer - iDrive(±current_limitクランプ)
```

- **摩擦フィードフォワードは廃止。** ブレークアウェイ電流は角度・方向依存で
  150〜950mA(2026-07-05電流ランプ実測)とばらつき、固定値FFは過大/過小どちらにも
  なって振動の原因になった。摩擦は定常外乱としてPI積分だけで吸収する。
  そのために `current_limit`(2000)は最悪ブレークアウェイの約2倍の余裕を持たせる。
- **最低ステア速度フロア(`steer_min_rpm`)。** 指令速度がステア約1rpm以下だと
  スティックスリップのリミットサイクルに入る。デッドバンド外では指令の大きさを
  最低2rpmに底上げし、デッドバンド内で0にする。終端接近を連続運動のまま行うのが目的。
- 個別モーターPI+瞬時rpm閾値キック方式は廃止済み(ノイズで左右非同期になり振動)。

## RoboMaster系オープン実装との比較と取り込み(2026-07-06)

DJI公式Development Board C例や大学チームのstandard_robot系に共通するM3508カスケード制御
(角度PID→速度PID→C620電流指令、1kHz)と本実装を比較した。構造(カスケード、速度PI、
摩擦FFなし、1kHz)は既に同等。以下の3点が本実装に無かったため導入した。

1. **積分項の独立クランプ(`mode_integral_limit`、RM系のmax_iout相当)。**
   従来は出力±current_limitに達したときだけ積分を止める条件付きアンチワインドアップで、
   固着中に積分が±2000まで成長できた。ブレークアウェイ実測最大950に対し、動き出しの
   瞬間に積分が過大トルクとして解放されるのがスティックスリップ階段・Ki=200発振の
   一因。クランプ値1200(最悪ブレークアウェイ950より上=静止摩擦には勝てる、
   current_limit=2000より下=解放時の跳びを制限)。
2. **合成電流飽和時のモード比例スケーリング+条件付き積分凍結。**
   従来はm1/m2を個別クランプしており、片側だけ飽和すると操舵/駆動トルク比が暗黙に
   歪む(操舵中の駆動が勝手に増減する交差干渉)。RM系の電力制限が全モーターを比例
   縮小するのと同様に、|iSteer|+|iDrive|>limitのとき両モード電流を共通係数で縮小し、
   トルク方向を保存する。飽和した次周期は両積分を凍結(条件付き積分)。
   ログ用に`torque_scaling_active`を出力へ追加。
3. **駆動(ホイール)目標のランプ(`wheel_accel_rpm_per_s`)。**
   ステア側と違い駆動目標はステップのままPIへ入っていた。実走テスト前に必要。
   初期値200rpm/s(未実測。駆動実走テストで調整すること)。

RM系にあるが採用しなかったもの: 速度ループKd(RM系でも実質0)、積分分離
(本実装は目標がランプで入るため誤差が大きく開かない)、目標角へのフィードフォワード
(steer_min_rpmフロアで代替済み)。

**単位の注意**: 本実装で「mA」と呼んでいる電流値はC620の生指令値(±16384=±20A)。
1カウント≈1.22mAなので、limit=2000は実際には約2.44A。内部的には一貫しているため
改名はしないが、実電流と比較するときは換算すること。

## 実験ログ(2026-07-05、+10°ステップ・wheel=0)

| # | 変更 | 結果 |
|---|---|---|
| 0 | Kp=5/Ki=10, maxSteer=1rpm, FFなし | ブレークアウェイ到達に~8秒(積分55mA/s)。到達後は誤差0.07°で安定保持 |
| 1 | Ki=100 | 収束~16秒。2.5秒周期のスティックスリップ階段(溜める→2°跳ぶ→積分崩壊) |
| 2 | maxSteer=5rpm, accel=20, angleKp=0.5 | ~13秒。終端で指令速度が低下し再固着→+2°オーバーシュート1回 |
| 3 | **steer_min_rpm=2.0, accel=50** | **~3.5秒、終端誤差0.37°、オーバーシュートなし。ベスト構成** |
| 4 | Ki=200 | **±2°の激しいリミットサイクル発振。電流±2000往復。即revert** |
| 5 | (2026-07-06)手回し点検OK後、mode_integral_limit=1200込みで再現確認(パラメータ変更なし) | **~3.25秒、終端誤差0.07〜0.16°、オーバーシュートなし。発振なし。イテレーション3(積分クランプ導入前)と同等以上** |
| 6 | steer_mode_ki: 100→125 | **~3.0秒、終端誤差0.02°。1サンプルのみ-0.107°の軽微なオーバーシュート(継続反転なし)。発振なし。イテレーション5より改善** |
| 7 | steer_mode_ki: 125→150(安全上限) | ~3.25秒、終端誤差0.332°。発振なしだがイテレーション6より悪化(Ki=100相当まで後退)。**steer_mode_ki=125が現時点のベストと確定、150へは戻さない** |

イテレーション4の発振直後、Ki=100へ戻した次の試験で角度が目標から-114°逆走して
発散ガード(12°)で停止した。発振で機構に何か起きた可能性があり、通電試験を中断して
手回し点検待ちとした。2026-07-06、ユーザーによる手回し点検で異常なしを確認し、
再開。イテレーション5で積分クランプ込みの再現に成功。

## 駆動モード(wheel≠0)ステップ応答テスト(2026-07-06)

操舵を起動角に保持したまま、wheel目標を0→50rpmへステップ指令(`wheel_accel_rpm_per_s`=200で
ランプ)。モード非干渉(純駆動でステアが動かないか)と`wheel_accel_rpm_per_s`/`drive_mode_ki`の
実機挙動を評価する新規テスト(`firmware/src/main.c`を書き換え)。ホイールは接地させず浮かせて実施。

| # | 変更 | 結果 |
|---|---|---|
| 8 | 初版: rpm誤差(ランプ後の瞬時値vs実測)が20rpmを超えたら即STOP | ランプが49rpmに達した時点(約245ms)で実測rpmがほぼ0のままerr=46rpmとなり即STOP。**モーターはほぼ無回転**(m1/m2実測rpm=0、電流もi1=i2=0まで戻る=ごく小電流のみ)。ブレークアウェイ電流(150〜950mA)にまだ届いていない段階での誤判定 |
| 9 | ガードに時間猶予1.5秒(`WHEEL_ERROR_CHECK_GRACE_MS`)を追加 | 猶予期間内に実際にモーターが動く兆候(m1実測56rpm、m2実測-101〜-252rpm)。同時に保持していたはずの操舵角が最大-0.615°ドリフト(モード間の機械的カップリングの可能性、非干渉性の検証項目として記録)。ただし`measured_wheel_rpm`の算出値が単発で300〜500rpm相当まで跳ね上がった直後にSTOP。**当初「フィードバックのノイズ/バグ」と誤診断したが、イテレーション10で否定(下記)** |

イテレーション9の直後、ユーザーから「(実機は)全然回ってすらいない」との指摘。イテレーション10の
開ループ試験でC620生フィードバックにはノイズ・異常値が一切出ないことを確認したため、
イテレーション9のスパイクは**フィードバックのノイズやデコードバグではなく、ブレークアウェイ
瞬間の実際の機械的キック(スティックスリップの解放)だった可能性が高い**と訂正する。
発散ガードは「ランプ済み目標との20rpm誤差」を見ていたため、このキック自体(30rpm超の
瞬間的な動き)がガードに引っかかって即STOPしていたと考えられる。

## 駆動(差動)電流のブレークアウェイ確認 — 開ループ(2026-07-06)

イテレーション9のスパイクの原因切り分けのため、PIを完全に排除した開ループ試験を実施。
`motor1=+I, motor2=-I`の純粋な差動電流を500raw/sでランプし、生のC620フィードバック
(motors[N].feedback.rpm/torque_current)をそのまま20ms周期でログした(`firmware/src/main.c`を
書き換え)。ホイールは接地させず浮かせて実施。

| # | 変更 | 結果 |
|---|---|---|
| 10 | 開ループ差動電流ランプ、生rpmを直接ログ | **電流852(raw、上限2000のうち)でm2rpm=-32を検出し正常にブレークアウェイ判定。** それまでm1/m2の生rpmは終始ほぼ0(±3程度のノイズのみ)で、イテレーション9で見た数百rpm相当の異常値は一切再現しなかった。**結論: C620フィードバック自体は健全。ホイールは実際に動く(壊れても固着してもいない)。単に静止摩擦を破るのに約850raw(現状のcurrent_limit=2000の半分弱)が必要で、閉ループ試験(イテレーション8/9)ではPIの積分がそこまで安定して到達する前に発散ガードに引っかかっていた** |

安全のため`CLOSED_LOOP_TEST_ENABLED=0`に戻して書き込み済み。次はこのブレークアウェイ電流
(~850raw、方向依存で変動しうる)を踏まえて、閉ループ側の発散ガード(瞬間的なブレークアウェイ
キックを誤検出しない設計に見直す)と`drive_mode_ki`/`wheel_accel_rpm_per_s`の再チューニングへ。

### イテレーション11: rpm発散ガード撤去、10秒完走(2026-07-06)

current_limitが既にハードクランプしているため、rpm誤差ベースの発散ガードは無駄と判断し撤去
(ユーザー指示)。ガードは角度発散(12°)・センサ/C620タイムアウト・B1・最大試験時間(10秒)のみに
縮小。閉ループのwheelステップテスト(操舵保持+wheel 0→50rpm)を再実行。

結果:
- **誤停止なく10秒間完走**(`STOP: max test duration reached`で正常終了。角度誤差は最大
  でも1.143°、12°のガードには遠く届かず)。
- m1/m2の実測rpmは試験中ずっと非ゼロで振れ続けた(例: 175, -208, 265, -183など)。
  イテレーション10で確認したブレークアウェイ(~850raw)は再現しており、ホイールは
  実際に動いている。
- **ただし滑らかに50rpmへ収束・保持する挙動ではなく、スティックスリップ的な断続動作**。
- **新知見: 保持していたはずの操舵角が、試験開始から終了まで継続的に±0.5〜1.1°の範囲で
  振動し続けた**(単発ドリフトではなく持続的な振動)。角度P制御が常にこの外乱を追いかけて
  `steer_rpm_command`が±2rpm(2000)の間を往復し続けている。差動機構の駆動→操舵への
  機械的カップリングが、想定より強く持続的であることを示す実測データ。
  `CENTRAL_COORDINATED_CONTROL.md`の非干渉性検証項目1の裏付けデータとして重要。

次: (1) この持続的な操舵振動の対策(カップリング補正項、またはangle_deadbandを広げて
振動域を許容するなど)。(2) スティックスリップを抑えて滑らかな50rpm定常回転に近づける
`drive_mode_ki`/`wheel_accel_rpm_per_s`のチューニング。

### 単一モーター速度制御の追試(イテレーション12〜17、2026-07-06)

ユーザー指摘(「実は全然回っていないのでは」「単一モーターでもrpm指定すれば摩擦関係なく
回るはずでは」「低速域が制御不能な領域なのでは」)を受け、二モーター差動を切り離し、
**motor1単体・motor2=0固定**で5種類のアーキテクチャを試した(`firmware/src/main.c`を都度書き換え)。

| # | アーキテクチャ | 結果 |
|---|---|---|
| 12 | 単純rpm PI(KP=5, KI=100、目標50rpmへランプ) | m1rpmが-95〜+309rpmで激しく振動、10秒間収束せず。integralが溜める→跳ぶ→崩壊を繰り返す典型的なスティックスリップ限界サイクル |
| 13 | +測定rpmへの一次LPF(τ=0.02s、mode_rpm_filter_tau_sと同値) | **改善なし**。振動は実際のブレークアウェイキック(センサノイズではない)そのものなので、フィルタでは消えないと確認 |
| 14 | +初期キック電流(1200raw固定→動き出し検知でPIへバンプレス引き継ぎ) | キック自体は成功(t=7msでrpm=14に到達)が、**PI移行後も同じ振動が継続**。「動き出すまでが遅い」問題とは別に、PIゲイン自体が発振の原因と確定 |
| 15 | 仮想シャフト位置追従(C620のrotor_angleフィードバックで目標位置を常時ランプ、位置誤差からP制御でrpm指令を生成し同じ内側PIへ) | **改善なし**。lagRev(位置ズレ)が0.13〜0.34回転の帯で振動し続け収束せず |
| 16 | 同上、目標を50→250rpmへ引き上げ(低速域回避の仮説検証) | **悪化**。lagRevが収束するどころか単調に増加し1.3回転超まで拡大、指令rpmが上限(400rpm)に張り付いたまま追いつけず。m1rpmの振れ幅も-141〜+554rpmに拡大。**低速域が原因という仮説は否定** |

**結論**: 5種類の外側アーキテクチャ(単純PI/フィルタ/キック/位置追従/高速目標)すべてで
同じ発振が形を変えて現れ続けた。共通する変数は内側電流PIのゲイン(KP=5, KI=100)のみであり、
アーキテクチャ変更では解決しないことを確認。ユーザーが目視した「モーターのガクガクした動き」は
指令送信の不連続性(バグ)ではなく、1kHzで正しく更新され続けている指令値そのものが
数百ms周期で大きく振動していることの物理的な現れと確認。

このまま無負荷ベンチでの深追いは費用対効果が低いと判断し、`CLOSED_LOOP_TEST_ENABLED=0`
(安全待機)で書き込み・verify・reset済み。次回再開する場合の候補:
KIを大幅に下げる(100→20〜30程度)実験は未実施のまま保留。実走行(接地・負荷あり)で
摩擦特性を取り直す方が優先度が高い可能性。

### 訂正: C620 rpmの19:1単位不一致(2026-07-06)

上記イテレーション12〜17では、C620が返すM3508ロータrpm(内蔵19:1減速前)を、
`motor_max_rpm=469`および運動学が扱う減速後出力軸rpmと直接比較していた。測定値が19倍の
単位不一致だったため、「250rpmでも悪化」「低速域原因説を否定」および内側PIだけを原因とした
結論は無効。履歴として表は残すが、ゲイン選定の根拠には使用しない。

measurement境界を`feedback.rpm / 19.0f`へ修正後の結果:

- 単一モーター目標50 output-rpm、Kp=5/Ki=20: 概ね47〜54rpmへ追従。
- 差動wheel、steer Kp=50/Ki=20、drive Kp=5/Ki=20、steer max/min=0.5/0rpm、
  steer accel=5rpm/s^2、angle Kp=0.1、current limit=2000、integral limit=1200:
  50/60/75/100/150/250rpmを各10秒完走し、概ね追従。
- 25rpmは停止・再始動の周期動作が残り不合格。40rpmは正式再試験が必要。
- 上記は無負荷・正転の探索結果。正式採用には正逆転を含む各点3/3合格が必要。

試験はRPM点ごとの短命エージェントへ分割し、1点最大2回、生ログはファイル保存して集計値だけを
親へ返す。COM/flash/駆動は`invoke-hardware-session.ps1`のmutexで直列化し、finallyで安全待機を
書き込む。別セッションが同じ`main.c`を編集している間は実機試験を開始しない。

## 電流ランプ特性化の実測(参考)

開ループで50mA/100msずつ増加、動き出し電流を記録(4試行、開始角度は毎回異なる):

- steer+: 500〜950 / steer-: 450〜950 / drive+: 400〜950 / drive-: 150〜950 mA
- 角度依存が大きい(局所的に硬い箇所がある)。単一のFF定数が成立しない根拠。
- drive方向の検出はC620 rpmノイズ(静止でも±50rpm瞬時)の影響を受けるため参考値。

## 安定実績パラメータ(main.c control_config、2026-07-06 イテレーション6時点)

```c
.motor_max_rpm = 469, .steer_max_rpm = 5, .steer_min_rpm = 2,
.steer_accel_rpm_per_s = 50, .wheel_accel_rpm_per_s = 200 /* 未実測 */,
.angle_kp_rpm_per_deg = 0.5, .angle_deadband_deg = 0.5,
.steer_mode_kp = 5, .steer_mode_ki = 125,   // 150は125より悪化、200は発振NG
.drive_mode_kp = 5, .drive_mode_ki = 100,   // wheel!=0未実施のため125への追随は未検証
.mode_integral_limit = 1200 /* 2026-07-06実機再現確認済み(イテレーション5) */,
.mode_rpm_filter_tau_s = 0.02, .current_limit = 2000, .steer_motor_sign = 1,
```

ベスト実績更新(2026-07-06、イテレーション6、steer_mode_ki=125): +10°ステップを約3.0秒、
終端誤差0.02°、1サンプルのみ-0.107°の軽微なオーバーシュート。イテレーション7でKi=150を
試したが3.25秒/0.332°まで悪化したため125を確定値とする。`drive_mode_ki`は同時に上げていない
(wheel=0のステアのみの試験のため未検証)。駆動実走試験を行う際に個別調整すること。

注意: `mode_integral_limit`(=1200)は2026-07-06のイテレーション5で積分クランプ込みの
実機再現に成功済み(挙動差なし)。

## テスト運用の注意

- テストアプリは起動時に1回だけ自動開始(目標=起動角+10°)。B1で中断ラッチ。
  固定タイムアウトは廃止(停止条件: B1・センサ異常・C620途絶・誤差12°超)。
- **ST-LINK VCPは未読データをバッファし、モニタ接続時に古いログを再生する。**
  新しい試験の `START:` 行(target=起動角+10°)より前の行は解析に使わない。
  これを見誤り「リセット後も発振継続」と誤診した事例あり。
- 調整の反復手順は `.claude/skills/gain-tuning/SKILL.md`(gain-tunerエージェント用
  ランブック)に固めてある。

## 安全状態

`src/main.c` の `CLOSED_LOOP_TEST_ENABLED` は既定0(B1を押しても電流0)。
監督付き試験時のみ1にする。現在は0で引き渡し済み。

## 次の課題

1. 発振後の機構点検(ユーザー手回し)→ 問題なければイテレーション3構成で再現確認
   (2026-07-06の積分クランプ込み。挙動差はiLimit=2000で切り分け)。
2. 駆動(差動)モードの実走テスト(これまでの調整は操舵のみ、wheel=0)。
3. 目標角の連続追従(ステップでなくランプ/正弦)での評価。
4. Ki 100〜150の間の詰め、angle_kpの引き上げ検討。
5. **接地移行**: 接地状態で電流ランプ特性化を再実行し、current_limit(ユーザー承認)/
   mode_integral_limit / steer_min_rpm を引き直してから再チューニング。
   角度ループはほぼ流用可の見込み。
6. **将来計画**: CALフェーズでの機構自己同定(ブレークアウェイ・時定数の自動測定→
   電流系パラメータの自動導出)と、荷重変動へのLESO/LADRC適用。
   `docs/control/CALIBRATION_AND_ADAPTATION_PLAN.md` 参照。

## wheel 40rpm単点試験(2026-07-07)

- 単位: C620 raw rotor rpmを19で除算してM3508出力軸rpmへ変換後、wheel rpmを評価。
- Run 1: steer Kp/Ki=50/20、drive Kp/Ki=5/20、current limit=2000、積分上限=1200。
  10秒完走、後半wheel平均33.999rpm、min/max=-0.032/243.561rpm、角度誤差peak
  1.670°、モーター非ゼロ率m1=32%/m2=34%。停止・再始動型スティックスリップのためFAIL。
- Run 2: drive Kiだけ20→30へ変更。実行ツールtimeoutかつログ未生成のため評価不能。
  追加駆動せずKi=20へ復帰した。
- 最終状態: `CLOSED_LOOP_TEST_ENABLED=0`をclean buildし、flash/verify/reset成功。

## wheel staircase下限探索(2026-07-07)

安全運用:
- 実機操作はすべて`firmware/scripts/invoke-hardware-session.ps1`経由。
- 有効化HEXを退避してからソースをsafe-idleへ戻し、試験終了後はsafe-idleを
  flash/verify/reset。最終状態も`CLOSED_LOOP_TEST_ENABLED=0`。

標準staircase(40/45/50/60/75/100/150rpm):
- ログ: `firmware/logs/staircase-2026-07-07T04-31-33-622Z.log`
- 全stepが`STEP_OK`で完走。
- `STEP_OK`直前1秒の評価では、40rpmも平均40.74rpm、p-p 15.07rpm、
  角度誤差max 0.97°で通過。45rpmは平均47.78rpm、p-p 8.05rpm、
  角度誤差max 1.76°。50rpm以上も全て通過。
- ただしstep全体の集計ではブレークアウェイ直後のキックを含むためp-pが大きく見える。
  `STEP_OK`直前の安定窓と、step全体の過渡を分けて評価する必要がある。

低速staircase(25/30/35/40rpm、一時変更):
- ログ: `firmware/logs/staircase-lowrpm-2026-07-07T04-34-11-016Z.log`
- 25rpm: `STEP_OK`、直前1秒平均23.98rpm、p-p 18.78rpm、角度誤差max 0.79°。
- 30rpm: timeout、終了時 measured 6.82rpm、angleErr 7.47°。
- 35rpm: `STEP_OK`、直前1秒平均37.37rpm、p-p 6.67rpm、角度誤差max 2.02°。
- 40rpm: timeout、終了時 measured 127.73rpm、angleErr 2.37°。step中の角度誤差maxは10.37°。

結論:
- 現ゲイン(drive Kp/Ki=5/20、steer Kp/Ki=50/20、steer max=0.5rpm)で、
  正転・無負荷・今回の姿勢では40rpm以上は通るが、30〜40rpm帯の再現性は未確定。
- 25/35 OK、30/40 timeoutという非単調な結果から、単純な最低rpmしきい値よりも
  始動角・局所摩擦・駆動→操舵カップリングの影響が支配的と見る。
- 次の試験ではdrive Kiを増やす前に、操舵保持側を少し強める
  (`angle_kp_rpm_per_deg`、`steer_max_rpm`、`steer_mode_ki`)か、
  角度誤差が大きいstepを早めにFAIL扱いするstep内ガードを追加する。

## 操舵保持強化と350rpmまでの確認(2026-07-07)

変更:
- `scale=`ログを追加し、`compact-test-log.ps1`でstep別スケーリング率を集計。
- step内角度誤差6°が300ms継続したら`STEP_FAIL: angle`で次stepへ進む。
- 操舵保持を強化:
  - `steer_max_rpm`: 0.5 -> 1.0
  - `angle_kp_rpm_per_deg`: 0.1 -> 0.2
  - `steer_mode_ki`: 20 -> 30

低速再試験(30/35/40rpm):
- ログ: `firmware/logs/staircase-lowrpm-steerhold-2026-07-07T04-42-02-928Z.log`
- 30rpm: timeout、終了時 measured 0rpm、angleErr -1.406°。
- 35rpm: timeout、終了時 measured 0.001rpm相当、angleErr 0.176°。
- 40rpm: `STEP_OK`、直前1秒平均39.37rpm、p-p 11.94rpm、角度誤差max 0.44°。
- 全体最大角度誤差3.43°、`scale=1`は0%。操舵外乱は改善したため、30/35rpmの失敗は
  角度保持ではなく駆動側stick-slipが主因。

中高速試験(40/75/150/250/350rpm):
- ログ: `firmware/logs/staircase-highrpm-steerhold-2026-07-07T04-44-49-432Z.log`
- 全step `STEP_OK`、`scale=1`は全step 0%。
- `STEP_OK`直前1秒:
  - 40rpm: 平均39.36rpm、p-p 9.34rpm、角度誤差max 0.70°
  - 75rpm: 平均69.23rpm、p-p 11.18rpm、角度誤差max 0.79°
  - 150rpm: 平均148.84rpm、p-p 20.77rpm、角度誤差max 0.53°
  - 250rpm: 平均239.55rpm、p-p 50.40rpm、角度誤差max 1.14°
  - 350rpm: 平均345.75rpm、p-p 81.13rpm、角度誤差max 0.79°

判断:
- 無負荷・正転の下限は暫定40rpm。30/35rpmは採用しない。
- 350rpmまでは電流飽和なしで通過。高速側のp-pは増えるが、操舵保持は良好。
- 次は500/750/1000rpm級へ段階拡張し、`motor_max_rpm=469`とdrive比32/11から来る
  wheel理論上限約1360rpmへ近づける。高速側では平均追従だけでなく、p-p増加、
  `scale=1`率、温度、角度保持を主要判定にする。

## 長時間・拘束領域staircase(2026-07-07)

ユーザー指摘: 各stepの動作時間が短く、定常状態に至る前に`STEP_OK`している可能性がある。
拘束領域の評価では、短い通過判定ではなく長時間保持でp-p、角度保持、飽和率を見る。

ハーネス変更:
- `STEP_TIMEOUT_MS=25000`
- `STEP_MIN_DWELL_MS=10000`
- `STEP_STABLE_MS=3000`
- 安定判定は要求targetではなく`output.wheel_rpm_command`基準に変更。
  `motor_max_rpm`で要求1400rpmが約1364rpmへ制限されるため、要求値との差を見続けると
  拘束領域を正常評価できない。
- `STEP_OK/STEP_FAIL`へ`cmd=`を追加。

結果:
- ログ: `firmware/logs/staircase-long-highrpm-constraint-2026-07-07T04-49-46-624Z.log`
- 要求500/750/1000/1200/1400rpm、全step `STEP_OK`。
- `STEP_OK`直前1秒:
  - 500rpm: 平均500.03rpm、p-p 5.06rpm、角度誤差max 0.53°、scale 0%
  - 750rpm: 平均749.72rpm、p-p 3.99rpm、角度誤差max 0.62°、scale 0%
  - 1000rpm: 平均1000.10rpm、p-p 2.96rpm、角度誤差max 0.62°、scale 0%
  - 1200rpm: 平均1200.27rpm、p-p 2.50rpm、角度誤差max 0.62°、scale 0%
  - 1400rpm要求: `cmd`約1363rpm、実測平均1363.49rpm、p-p 1.86rpm、
    角度誤差max 0.62°、scale 0%
- step全体のfinal-halfでは1400rpm要求stepでscale 0.8%。安定窓では0%。

判断:
- 無負荷・正転では40〜約1360rpmまで安定制御できている。
- 1400rpm要求は`motor_max_rpm=469`とdrive比32/11から来る上限拘束に入り、
  制御器は正しく`wheel_rpm_command`を約1364rpmへ制限している。
- 次の必須確認は逆転側。同じ長時間保持で-40/-500/-1000/-1400rpmを確認し、
  方向依存の摩擦・カップリング・電流余裕を切り分ける。

## 逆転代表点確認(2026-07-07)

負方向の安定判定で許容幅が常に10rpmになる問題を修正し、`wheel_tolerance`を
`abs(effective_target)`基準へ変更した。

結果:
- ログ: `firmware/logs/staircase-reverse-representative-2026-07-07T04-55-26-552Z.log`
- 要求 -40/-500/-1400rpm、全step `STEP_OK`。
- `STEP_OK`直前1秒:
  - -40rpm: 平均 -42.39rpm、p-p 9.02rpm、角度誤差max 0.53°、scale 0%
  - -500rpm: 平均 -500.31rpm、p-p 1.90rpm、角度誤差max 0.62°、scale 0%
  - -1400rpm要求: `cmd`約 -1363rpm、実測平均 -1362.55rpm、p-p 2.26rpm、
    角度誤差max 0.70°、scale 0%

判断:
- 逆転側も代表点では問題なし。
- 無負荷では正逆とも `|wheel rpm|=40〜約1360rpm` を安定制御できる。
- 次は接地/拘束状態で、同じ`ωw, θs`制御が温度・電流余裕・低速stick-slipの面で成立するか確認する。

## wheel 500rpm + steer +10deg 同時指令(2026-07-07)

接地試験ができないため、無負荷で「`ωw`を出しながら`θs`を動かす」確認へ移行。

試験:
- `ωw=500rpm`
- 起動角から`θs=+10°`
- 長時間保持ハーネスを1stepにして流用。

注意:
- 既存のstep内角度誤差6°/300ms FAILは、角度step試験ではstep投入直後に当然発火する。
  初回ログ`theta-step-wheel500-2026-07-07T05-01-36-470Z.log`はこの理由で評価不能。
- 再試験では`STEP_ANGLE_FAIL_DEG_MILLI=12000`へ緩和。

結果:
- ログ: `firmware/logs/theta-step-wheel500-retry-2026-07-07T05-02-45-975Z.log`
- `START: angle=185.186° target=195.186° wheelTarget=500`
- `STEP_OK: cmd=500.000rpm measured=499.349rpm angleErr=0.156°`
- 100msログ基準で角度誤差は約0.9sで2°以内、約1.0sで1°以内/0.5°以内。
- final-half wheel平均500.111rpm、p-p 9.914rpm、角度誤差max 0.771°、
  scale 0%、maxTemp 29°C。

判断:
- 無負荷では`ωw=500rpm`を維持しながら`θs=+10°`へ収束できる。
- 次は`θs`往復(+10/-10/0)または`ωw=40/1200rpm`代表点で同じ角度stepを確認する。
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

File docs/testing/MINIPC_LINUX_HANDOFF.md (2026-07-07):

# mini PC Linux test handoff

このメモは、Linux mini PC 上の別 Codex セッションへ渡すための引き継ぎ。

## 現状

- 対象: Differential Swerve Drive の単体ユニット評価。
- ユニットMCU: NUCLEO-G474RE / STM32G474。
- 中央CAN: FDCAN1(PA11/PA12)、CANable 経由で mini PC から送る。
- C620 CAN: FDCAN2。
- CAN bitrate: classic CAN 1 Mbps。
- unitId: `1`。
- 最新ワークツリーのファームは、起動時 disabled、`SET_TARGET` と `UNIT_CTRL enable` でのみ駆動する。
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

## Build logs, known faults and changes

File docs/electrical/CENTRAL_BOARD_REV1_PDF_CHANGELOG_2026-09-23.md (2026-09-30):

> **2026-09-29最新版:** `output/pdf/CENTRAL_BOARD_REV1_SCHEMATIC_2026-09-29.pdf`（15ページ）。全ページを直接ベクター描画し、文字サイズ10〜23pt、Teensy全端子/周辺回路とE-stop外部配線/監視/driverを分離。GPIO4組転記案とPMD22現物情報を反映。以下は旧版の改訂履歴。

> **コネクタ配線追記:** 整理版7ページにJ401全4pinとNCループ/監視素子、8ページにJ403入力・J402コイル2線・J401往復・監視分岐・独立LED保護の接続を図示（2026-09-26）。

> **最新：2026-09-26整理版、全12ページ。** 旧16ページ版を機能順に再構成。USB/VINとコイル電流経路を描き直し、ARMをE-stopページ、JP505をI/Oページへ統合。旧版のページ番号は以下の履歴に限る。未確定設計を12ページへ集約。

> **GUI共通ARM反映済み（2026-09-26）:** 最新PDFは16ページ。6/11ページにGUIとSW211の共通判定を追記し、16ページにARM/RUN分離・復帰条件・旧要求破棄・実装状況を追加。

> 2026-09-26更新: 最新PDF S04AはLTV-817Sのループ1ch監視。J401は4pin、ボタン個別/予備監視は省略。Teensy pad6/7は予約。以下の4ch記述は改訂前の履歴。

# 中央基板 Rev.1 人が読む回路図PDF 改訂記録 (2026-09-23)

> 2026-09-26追記: 最新版は`output/pdf/CENTRAL_BOARD_REV1_SCHEMATIC_2026-09-26.pdf`（15ページ）。USB側U102/R107〜R112/C106〜C108/TP106を14ページ、GPIO VCC選択JP505を15ページに追加。Teensy pad11はUSB fault入力候補へ更新（提案）。旧版PDFは履歴として保持。仮配置プロジェクトにも同じ12部品を追加済み（未配線）。

対象PDF: `output/pdf/CENTRAL_BOARD_REV1_SCHEMATIC_2026-09-23.pdf` (A3横13ページ)。生成器: `tmp/pdfs/build_central_board_rev1_schematic_2026_09_23.py`。2026-09-14版PDF/生成器は保存した。中央KiCad回路図・PCBの変更は本作業に含まれない。

## 変更点

- 5V入力/eFuse、USB diode-OR、6本のPPTC枝を拡大ページへ分離し、部品・ピン・ネットを手入力で追いやすくした。外部`SD-25B-5`の5V入力を維持する。
- **同日最終決定**: CAN1↔ODOM V2、CAN3↔駆動V2、CAN2↔自己給電LED/スイッチングノードの専用CANポートを、すべて横向きJST GH3の`1=COMM_A、2=COMM_B、3=GND`に統一した。5V/GND給電ハーネスは別に維持し、CANのGND線を負荷電流の帰路にしない。J323汎用拡張だけは4pin `+5V_EXP/GND/COMM_A/COMM_B`を維持する。CANトランシーバ、TVS、終端の共通回路を独立ページへ配置した。
- 旧J402 5線の別体`CONTACTOR_DRIVER`案を削除。J402をE228コイル2線の暫定ポート、J403を24V制御入力の暫定ポートとし、中央基板上のU402 `SN74AHCT1G125DBVR`、Q401 `IRLML0100TRPBF`、入力/ゲートプルダウン、ゲート抵抗をピン番号とともに描いた。コイル用ヒューズF401とクランプD4xxは配置候補を示すが、型番/定数は未選定。クランプは破線の未決定素子として描き、短絡配線ではないと注記した。
- E-stop 2個のNC直列接点によるコイル供給遮断を、Teensy/CANを通らない物理経路として記載した。LTV-847Sは診断専用で、チャンネルごとのLED/トランジスタピン対を維持する。`MOTOR_PWR_EN`はTeensy pad 4 / pin 2から中央U402へ直結し、Reset/Hi-Z/LowでQ401 OFFを確認対象とした。
- E228主接点の専用フィードバック監視は載せない。J401の補助接点入力はE-stopボタン用であり、コンタクタ接点監視ではない。制御5Vと中央↔駆動CANはOFF指令後も生かし、駆動MCUから中央へC620応答消失を補助診断として報告する。表示は`OFF指令中・C620応答なし`とし、CAN無応答だけを根拠に`遮断確認済み`としない。中央↔駆動CAN自体が不通なら状態を`不明/古い情報`として区別する。ハードNCループ、Reset/Hi-Z時OFF、明示的な再アームは維持する。
- PJRC公式寸法図に基づき、Teensy 4.1のソケット列中心間を**15.24 mm**に訂正。旧文書の17.78 mmは基板幅であり列間隔ではない。新しい`DifferentialSwerve:Teensy41_Socket_2x24`の使用と、対応する単一48pinシンボルが必要なことを示した。既存中央PCBのJ3/J4位置はTeensyを装着できないため流用しない。
- 外部I/Oの図を「1信号の例」と明示し、J501-J507の実際のpin数・順序を別表にした。13ページ全体で大きな図と注記を分け、ページ番号と参照先を付けた。

## KiCad転記前の未確定事項

1. 専用CANの横向きJST GH3基板側/相手ハウジング/圧着端子/footprintのpin 1向きとケーブル視点を照合する。J323の4pin pin順を流用しない。
2. F401の型番・定格・配置、LED枝の保護、24V制御供給源の最大条件。
3. E228コイルのクランプ方式/極性/定数/実装場所。E-stop時の解放時間、Q401のVDSピークを測定して決める。
4. J402/J403の正式MPN・pin順・キー、コイル線と24V帰路のハーネス。
5. 5V制御GND、24Vコイル帰路、各CAN参照GNDの結合点。コイル電流を静かな制御GNDに直列に流さない。
6. Teensyソケット実部品とランド/ドリルの適合、VUSBパッド取り出し方法。組立前に1:1印刷で確認。
7. F205/F206の実負荷・突入、Matek I2Cのプルアップ電圧、U401のfootprint。
8. U402の電源投入/遮断過渡と`MOTOR_PWR_EN`のReset/Hi-Z時OFFを実機で確認。

部品ピン・仕様の確認元: [TI SN74AHCT1G125](https://www.ti.com/lit/ds/symlink/sn74ahct1g125.pdf)、[Infineon IRLML0100](https://www.infineon.com/assets/row/public/documents/24/49/infineon-irlml0100-datasheet-en.pdf)、[PJRC Teensy 4.1寸法図](https://www.pjrc.com/teensy/dimensions_teensy41.png)、[PJRCソケット情報](https://www.pjrc.com/store/socket_24x1.html)。他の旧版から維持した回路値は`CENTRAL_BOARD_REV1_KICAD_ENTRY_REFERENCE.md`の出典を参照する。

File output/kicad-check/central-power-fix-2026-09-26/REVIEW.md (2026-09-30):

# 中央仮配置 電源回路 修正・確認（2026-09-26）

## 対象と保存

`hardware/central-board-placement` のユーザー保存18:40:19版を退避して修正。既存配置を維持し、生成器による再生成は行っていない。退避は `before/`。

## 修正

- U101 EN/UVLO・OVLO分圧鎖を接続表どおりに結線。
- U102のVUSB入力、SYS出力、EN分圧、ILMと出力コンデンサのGND、外部5V優先OVLO分圧、3.3V fault pull-upを補完。
- F205を1206L075/16WR（0.75A）へ統一。余分なF207を除き、F205後にD101とTeensy枝LEDを接続。
- S02Bの旧給電枝の重複22部品、不要なTP211〜213を除去。現行枝はS02Aに保持。
- GND_CTRLと供給ネット名を統一。Teensyの電源・fault端子と残す電源TPへ同名ネットを割当。
- IC1をU101に復帰。両eFuseにプロジェクト内footprint `DifferentialSwerve:TPS25947_RPW_10Pin`を割当。
- Part Loaderの14ランドのうち11→10、12→1、13→4、14→7へ番号を整理。銅箔・マスク・ペーストの形状と位置は元データを保持。シンボルは実端子1〜10とし、3/10はNC。共有SamacSysライブラリは変更していない。

## 確認結果

- KiCad netlistで主要65接続、内部6ネット、Unit/ODOM給電4枝、eFuse全端子を照合。
- 電源シートS02AのERC違反0件。プロジェクト全体は455→383件。未配線CAN/安全/I/O等が残り、完成・製造可能の判定ではない。
- 実部品174個、重複Refなし。両eFuseはpin/pad番号1〜10で一致し、14個の銅箔ランドの幾何形状は取得元と一致。
- SVGを出力し電源部を目視確認。追加ラベルの近傍は混み合うため、今後の作図整理対象。
- 証跡: `after.net`、`after-erc.rpt`、`audit.json`、`svg/`。

## 残る事項

C101/C104の購入型番・footprint、J102のVUSB取出し方法、USB経路の許容電流と実負荷、PCB上の配置・配線・DRC・実機評価は未完了。USB fault pad11は資料の提案割当を反映した状態。

KiCadで既に開いている場合は、古い画面を保存せず回路図を閉じて再読込すること。

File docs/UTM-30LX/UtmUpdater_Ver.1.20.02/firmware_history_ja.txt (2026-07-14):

UTM-30LX (Top-URG) ファームウェア更新履歴      2013-07-16 北陽電機(株)

2013-07-16 Version 1.20.02
    * 修正: 検査モードでのバグ

2013-04-23 Version 1.20.01
    * 修正: モータ異常で起動しないバグ

2012-12-17 Version 1.19.01
    * 修正: ノイズによる内部チップがリセットされる問題の対策 
    * 修正: 文字列を付けた QT コマンド応答の文字列の前に改行が入るバグ

2010-07-09 Version 1.18.01
    * 修正: DMA 転送によるタイムスタンプ異常
    * 修正: 正常時に 46, 75 のエラーが出力されたバグ
    * 修正: シリアル番号の先頭文字を 'H' に訂正

2010-02-22 Version 1.17.01
    * 追加: FRAM のライトプロテクト機能を追加

2010-01-19 Version 1.16.02
    * 追加: リブート用の RB コマンドに対応
    * 追加: 太陽光などの外乱光やセンサ同士の干渉に対する対策の強化
    * 追加: 電源電圧が規格値より低下したときの FRAM の書き換わり防止対策
    * 修正: MD コマンド応答の一部が送信されなかったバグ
    * 修正: MD コマンド応答が QT コマンドにより停止されなかったバグ
    * 修正: VV コマンド応答の通信プロトコルを 2.1b から 2.0 に訂正
    * 修正: 網のフェンスや鉄格子などに対して複数の反射光が検出された時に
            距離データが扇型になったバグ

2009-04-17 Version 1.15.05 (P.1.05) 
    * 修正: II コマンドの SUM チェックコードが誤っていたバグ
    * 修正: II コマンド応答から通信速度(SBPS) が抜けていたバグ
    * 修正: II コマンド応答で動作モードが誤っていたバグ
    * 修正: TM コマンド応答の改行コードが CR(0x0D) になっていたバグ
    * 修正: MD コマンドの最後の応答データがずれていたバグ
    * 追加: MD コマンド応答中に TM コマンドを受け付ける
    * 追加: MD コマンド応答中に新たな MD コマンドを受け付けて取得範囲の変更を可能にする
    * 修正: ME コマンドの残り返信回数が更新されなかったバグ
    * 修正: ME コマンドの応答中に QT コマンドを受信すると
            ME と QT の返信電文が混在していたバグ
    * 追加: FRAM のプロテクトを強化

2008-11-04 Version 1.12.00 (M.1.00bt2)
    * 修正: MD コマンド応答中に USB ケーブルが抜かれると再接続後にセンサが認識されなかったバグ
    * 修正: 受信データのサイズが 64 byte の倍数のときに通信が止まっていたバグ
    * 修正: TM コマンド受信後にレーザが消灯されなかったバグ
    * 追加: 故障コード

2008-04-21 Version 1.11.59 (L.1.59)
    * 初版

注意事項
    * ME コマンドでは通信データサイズが大きくなるために毎スキャン全周ステップのデータを送信できない
      場合がありますので，取得範囲を調節してご利用することを推奨します.
      また，通信状況などにより通信が遅れると，途中から次のスキャンのデータで上書きする問題が発生しています．
      今後の修正で上書きの発生をなくし、送信できなかったデータがあることをステータスなどで示す予定です．

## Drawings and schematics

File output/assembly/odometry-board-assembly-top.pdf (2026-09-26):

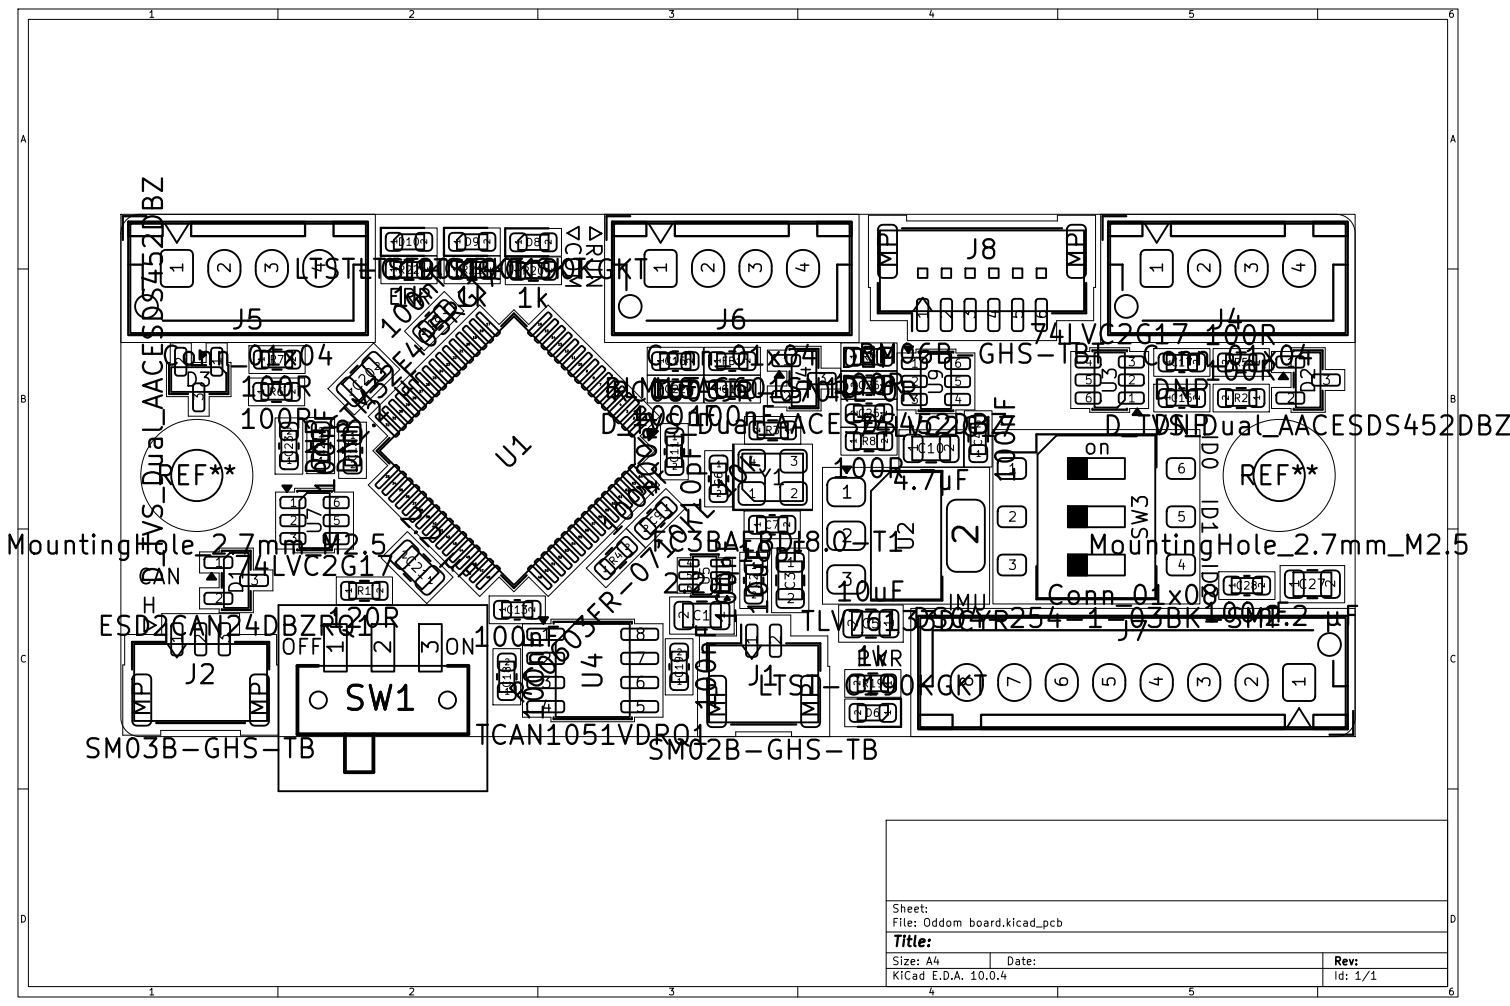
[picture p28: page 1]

Size: A4 | Rev:
KiCad E.D.A. 10.0.4 | Id: 1/1

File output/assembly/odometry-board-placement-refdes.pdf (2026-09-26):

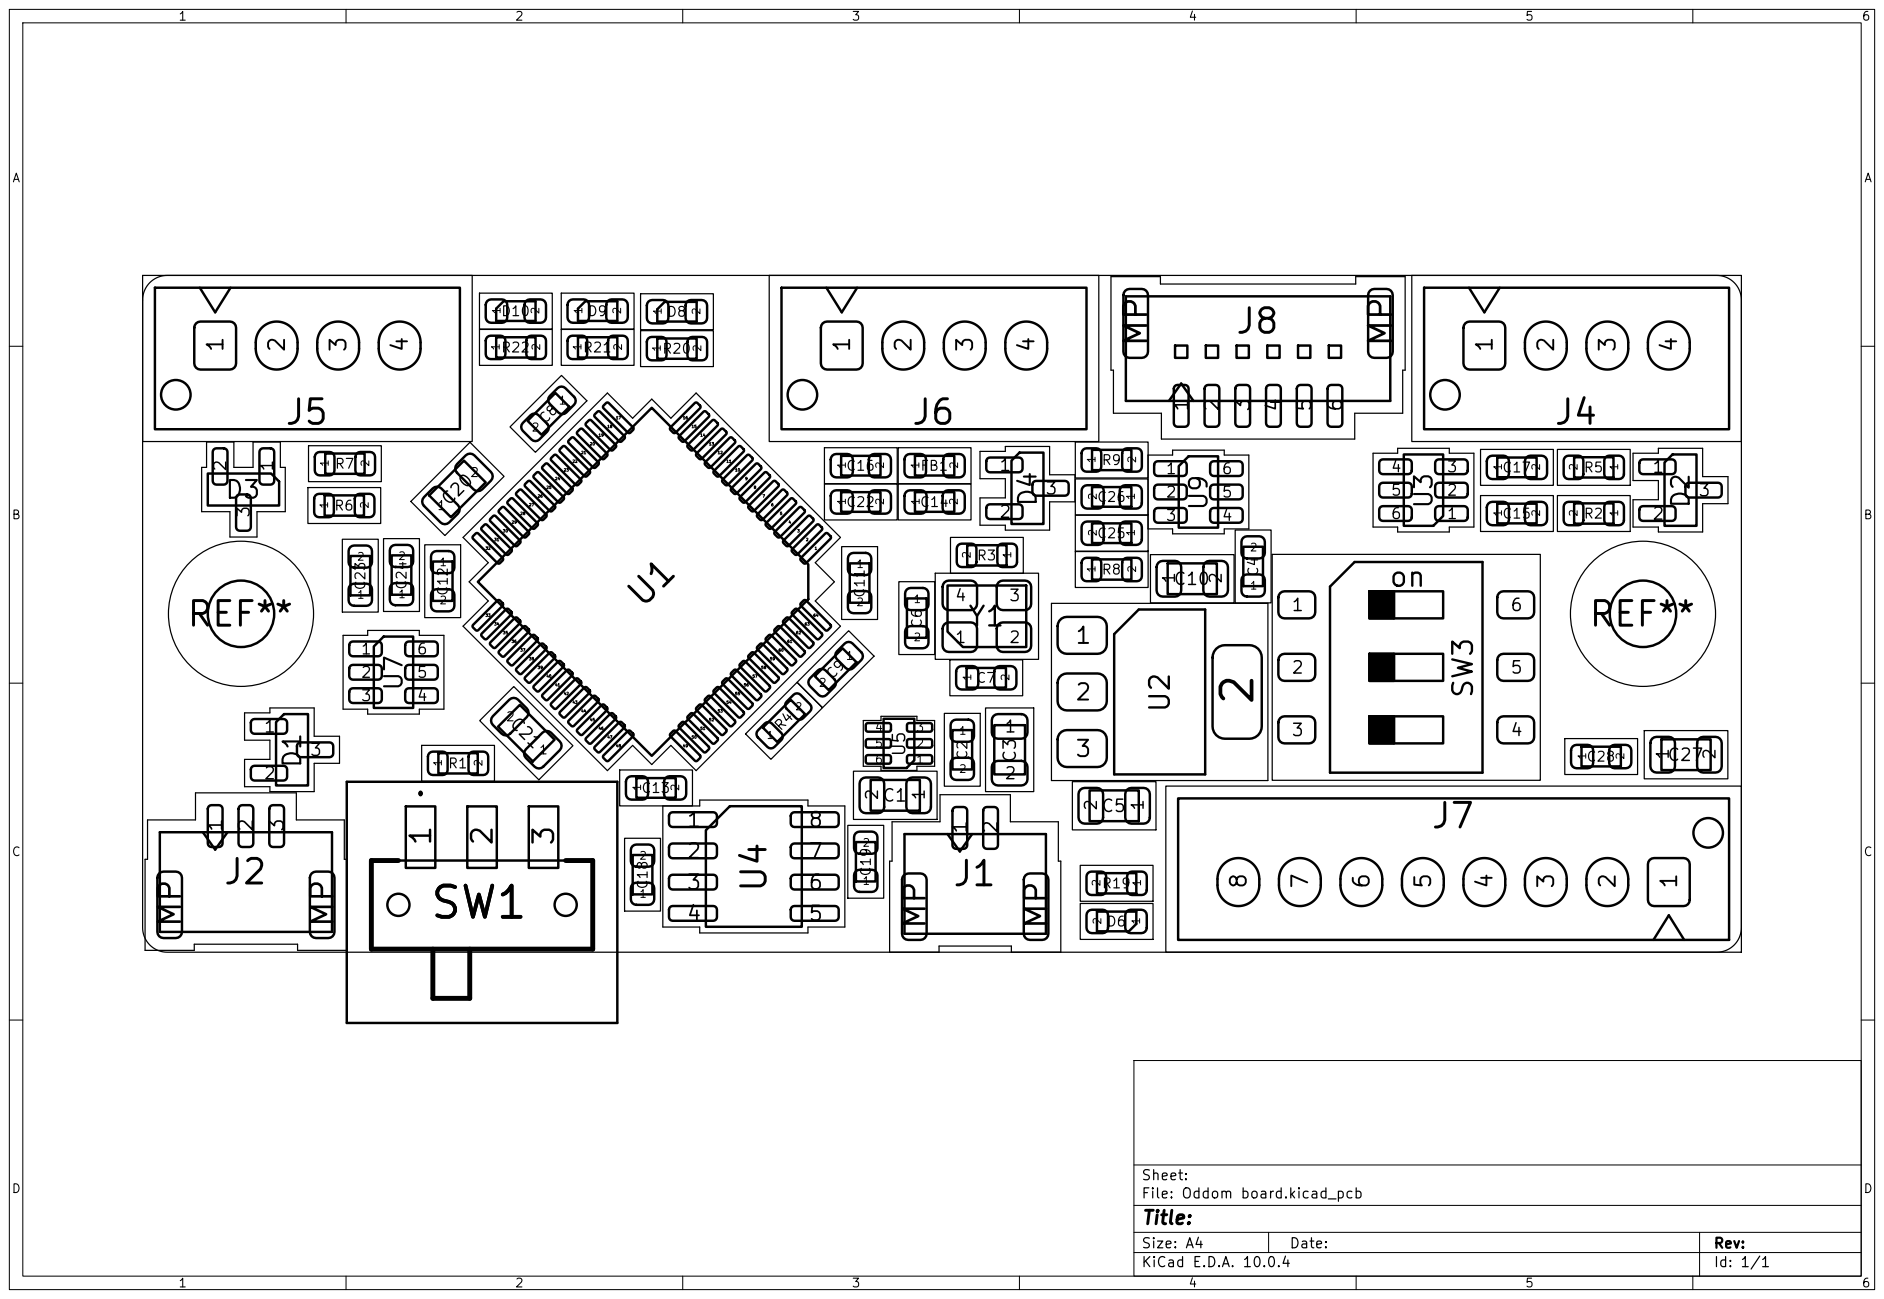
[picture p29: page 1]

Size: A4 | Rev:
KiCad E.D.A. 10.0.4 | Id: 1/1

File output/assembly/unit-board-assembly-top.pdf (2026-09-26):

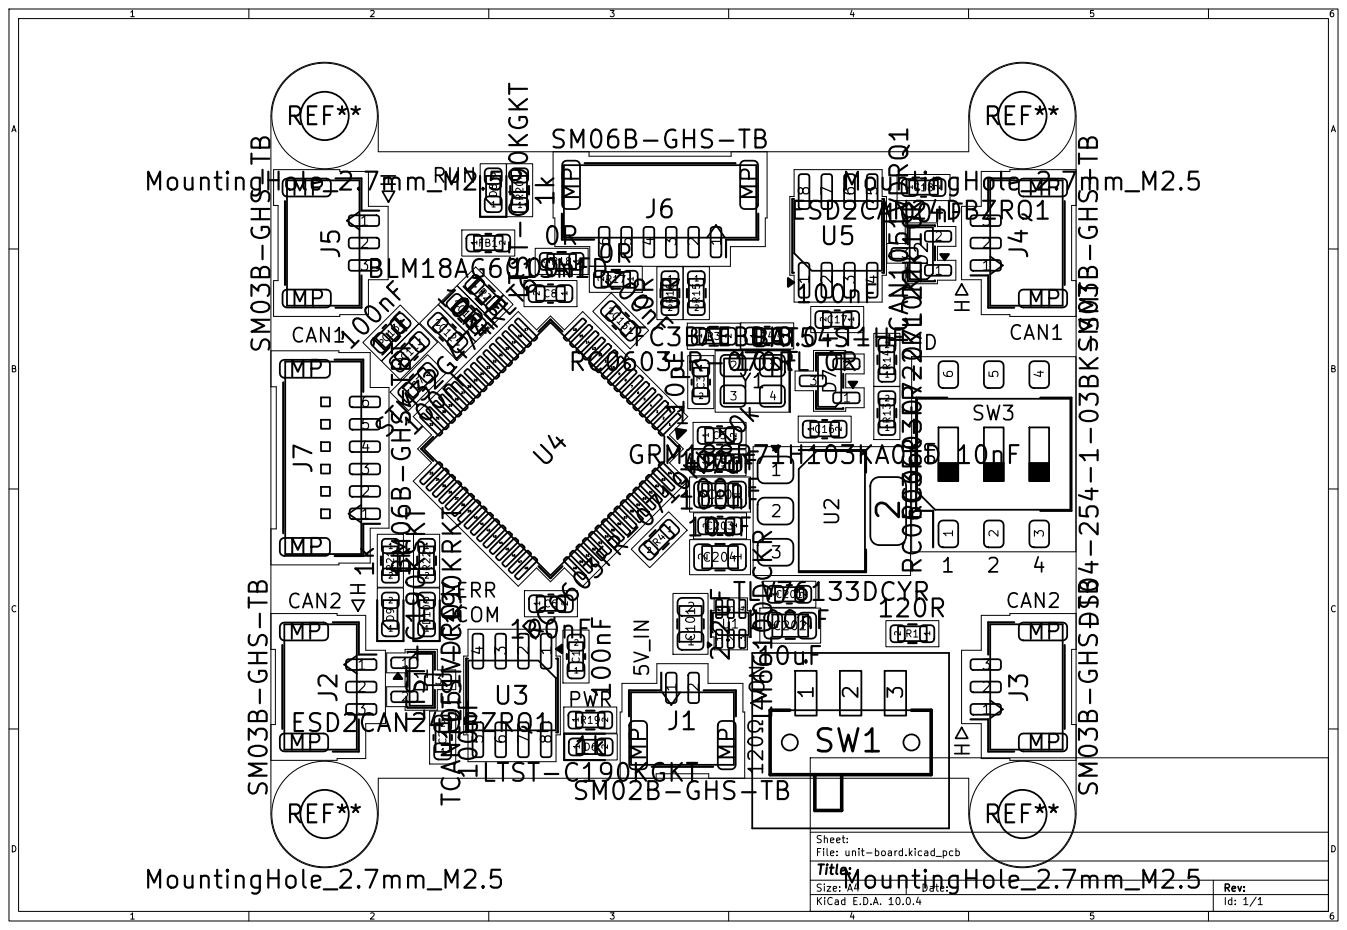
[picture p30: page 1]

Size: A4 | Rev:
KiCad E.D.A. 10.0.4 | Id: 1/1

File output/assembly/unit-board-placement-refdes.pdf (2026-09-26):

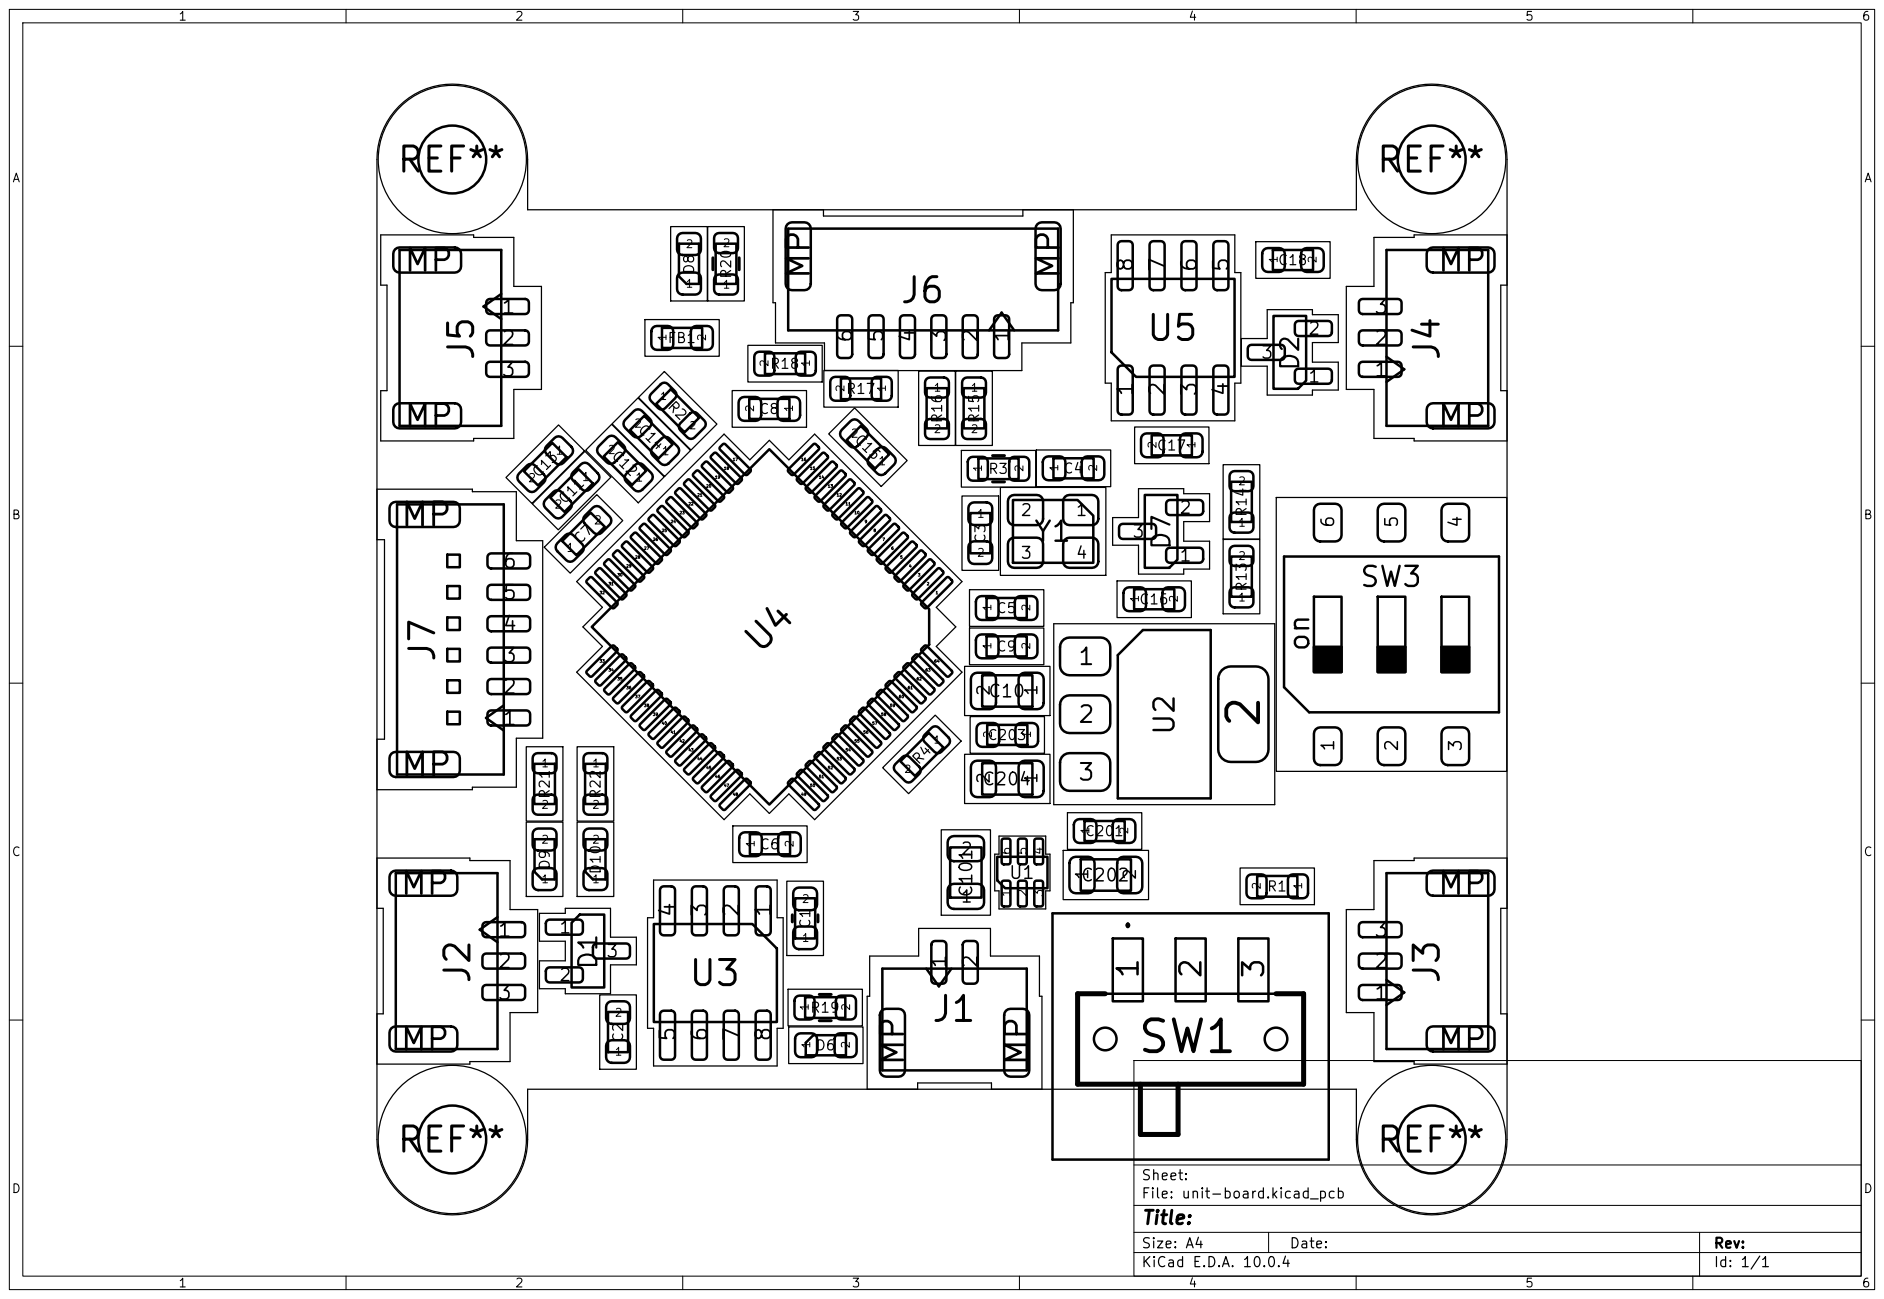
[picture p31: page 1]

Size: A4 | Rev:
KiCad E.D.A. 10.0.4 | Id: 1/1

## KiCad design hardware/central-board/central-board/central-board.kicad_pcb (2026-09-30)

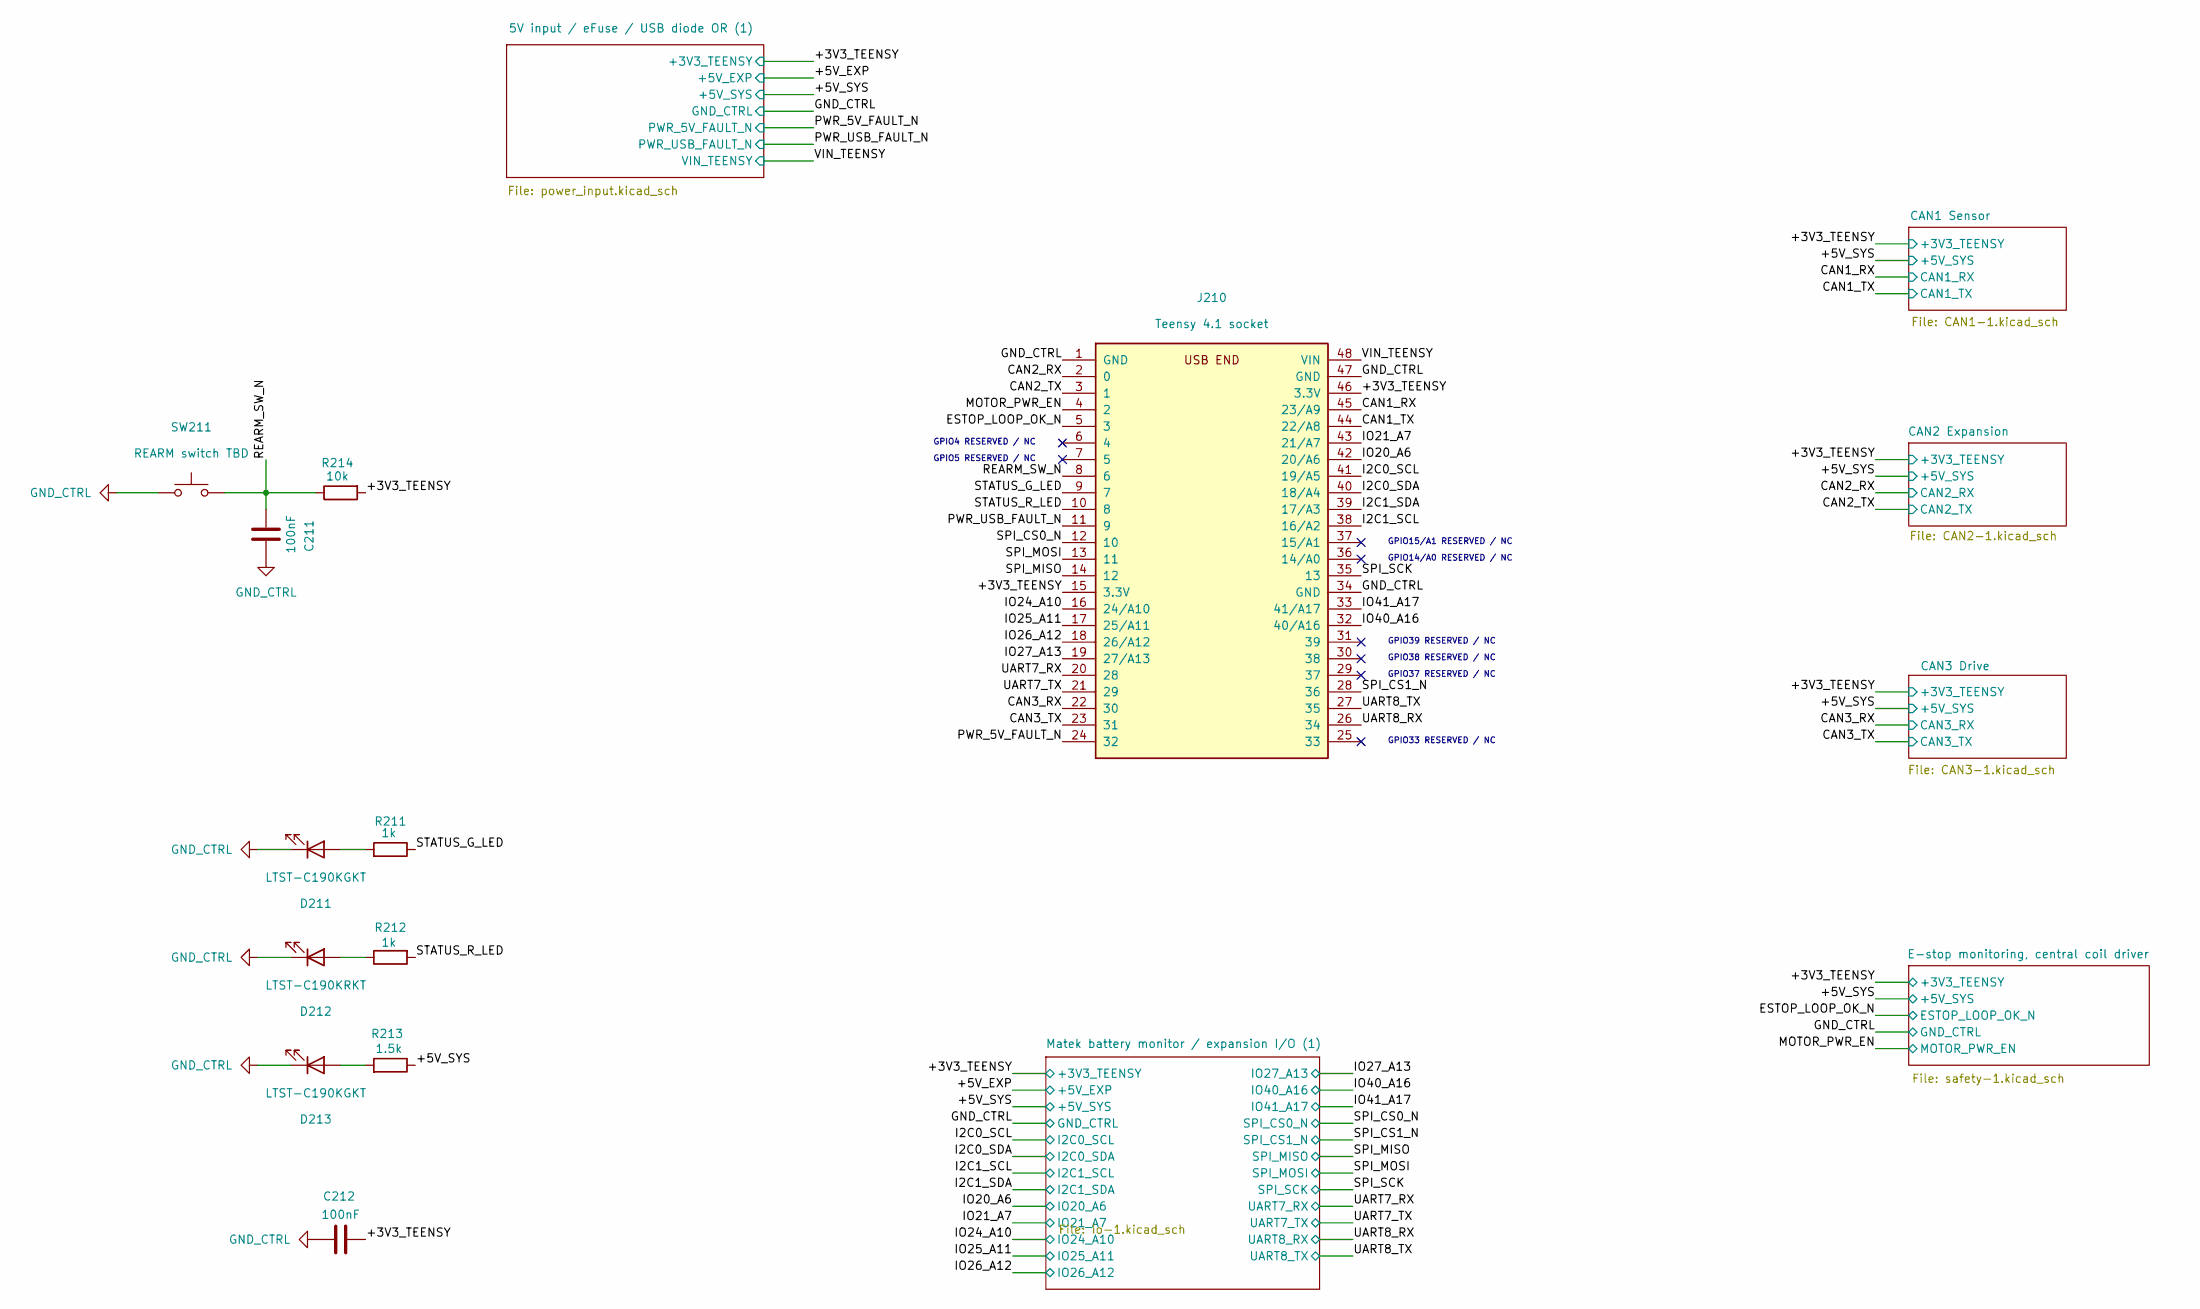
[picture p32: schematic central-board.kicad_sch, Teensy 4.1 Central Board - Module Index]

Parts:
C211, C212: 100nF; C_0603_1608Metric
D211, D213: LTST-C190KGKT; LED_0603_1608Metric
D212: LTST-C190KRKT; LED_0603_1608Metric
J210: Teensy 4.1 socket; Teensy41_Socket_2x24
R211, R212: 1k; R_0603_1608Metric
R213: 1.5k; R_0603_1608Metric
R214: 10k; R_0603_1608Metric
SW211: REARM switch TBD

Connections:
/+3V3_TEENSY: C212.1, J210.15 (3.3V), J210.46 (3.3V), R214.2; also elsewhere on the board
/+5V_SYS: R213.1; also elsewhere on the board
/CAN1_RX: J210.45 (23/A9); also elsewhere on the board
/CAN1_TX: J210.44 (22/A8); also elsewhere on the board
/CAN2_RX: J210.2 (0); also elsewhere on the board
/CAN2_TX: J210.3 (1); also elsewhere on the board
/CAN3_RX: J210.22 (30); also elsewhere on the board
/CAN3_TX: J210.23 (31); also elsewhere on the board
/ESTOP_LOOP_OK_N: J210.5 (3); also elsewhere on the board
/I2C0_SCL: J210.41 (19/A5); also elsewhere on the board
/I2C0_SDA: J210.40 (18/A4); also elsewhere on the board
/I2C1_SCL: J210.38 (16/A2); also elsewhere on the board
/I2C1_SDA: J210.39 (17/A3); also elsewhere on the board
/IO20_A6: J210.42 (20/A6); also elsewhere on the board
/IO21_A7: J210.43 (21/A7); also elsewhere on the board
/IO24_A10: J210.16 (24/A10); also elsewhere on the board
/IO25_A11: J210.17 (25/A11); also elsewhere on the board
/IO26_A12: J210.18 (26/A12); also elsewhere on the board
/IO27_A13: J210.19 (27/A13); also elsewhere on the board
/IO40_A16: J210.32 (40/A16); also elsewhere on the board
/IO41_A17: J210.33 (41/A17); also elsewhere on the board
/MOTOR_PWR_EN: J210.4 (2); also elsewhere on the board
/PWR_5V_FAULT_N: J210.24 (32); also elsewhere on the board
/PWR_USB_FAULT_N: J210.11 (9); also elsewhere on the board
/REARM_SW_N: C211.1, J210.8 (6), R214.1, SW211.1
/SPI_CS0_N: J210.12 (10); also elsewhere on the board
/SPI_CS1_N: J210.28 (36); also elsewhere on the board
/SPI_MISO: J210.14 (12); also elsewhere on the board
/SPI_MOSI: J210.13 (11); also elsewhere on the board
/SPI_SCK: J210.35 (13); also elsewhere on the board
/STATUS_G_LED: J210.9 (7), R211.1
/STATUS_R_LED: J210.10 (8), R212.2
/UART7_RX: J210.20 (28); also elsewhere on the board
/UART7_TX: J210.21 (29); also elsewhere on the board
/UART8_RX: J210.26 (34); also elsewhere on the board
/UART8_TX: J210.27 (35); also elsewhere on the board
/VIN_TEENSY: J210.48 (VIN); also elsewhere on the board
GND_CTRL: C211.2, C212.2, D211.1 (K), D212.1 (K), D213.1 (K), J210.1 (GND), J210.34 (GND), J210.47 (GND), SW211.2; also elsewhere on the board
unnamed: D211.2 (A), R211.2
unnamed: D212.2 (A), R212.1
unnamed: D213.2 (A), R213.2

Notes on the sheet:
GPIO38 RESERVED / NC
GPIO15/A1 RESERVED / NC
GPIO39 RESERVED / NC
GPIO14/A0 RESERVED / NC
GPIO33 RESERVED / NC
GPIO5 RESERVED / NC
GPIO37 RESERVED / NC
GPIO4 RESERVED / NC

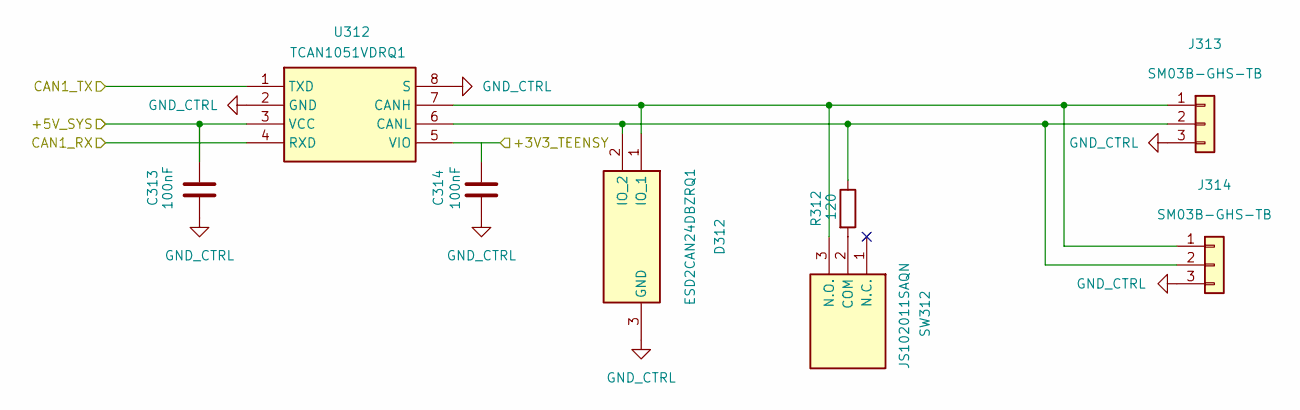
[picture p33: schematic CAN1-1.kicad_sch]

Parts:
C313, C314: 100nF; C_0603_1608Metric
D312: ESD2CAN24DBZRQ1; SOT-23
J313, J314: SM03B-GHS-TB; JST_GH_SM03B-GHS-TB_1x03-1MP_P1.25mm_Horizontal
R312: 120; R_0603_1608Metric
SW312: JS102011SAQN
U312: TCAN1051VDRQ1; SOIC-8_3.9x4.9mm_P1.27mm

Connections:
/+3V3_TEENSY: C314.1, U312.5 (VIO); also elsewhere on the board
/+5V_SYS: C313.1, U312.3 (VCC); also elsewhere on the board
/CAN1_RX: U312.4 (RXD); also elsewhere on the board
/CAN1_TX: U312.1 (TXD); also elsewhere on the board
GND_CTRL: C313.2, C314.2, D312.3 (GND), J313.3, J314.3, U312.2 (GND), U312.8 (S); also elsewhere on the board
unnamed: D312.1 (IO_1), J313.1, J314.1, SW312.3 (N.O.), U312.7 (CANH)
unnamed: D312.2 (IO_2), J313.2, J314.2, R312.1, U312.6 (CANL)
unnamed: R312.2, SW312.2 (COM)

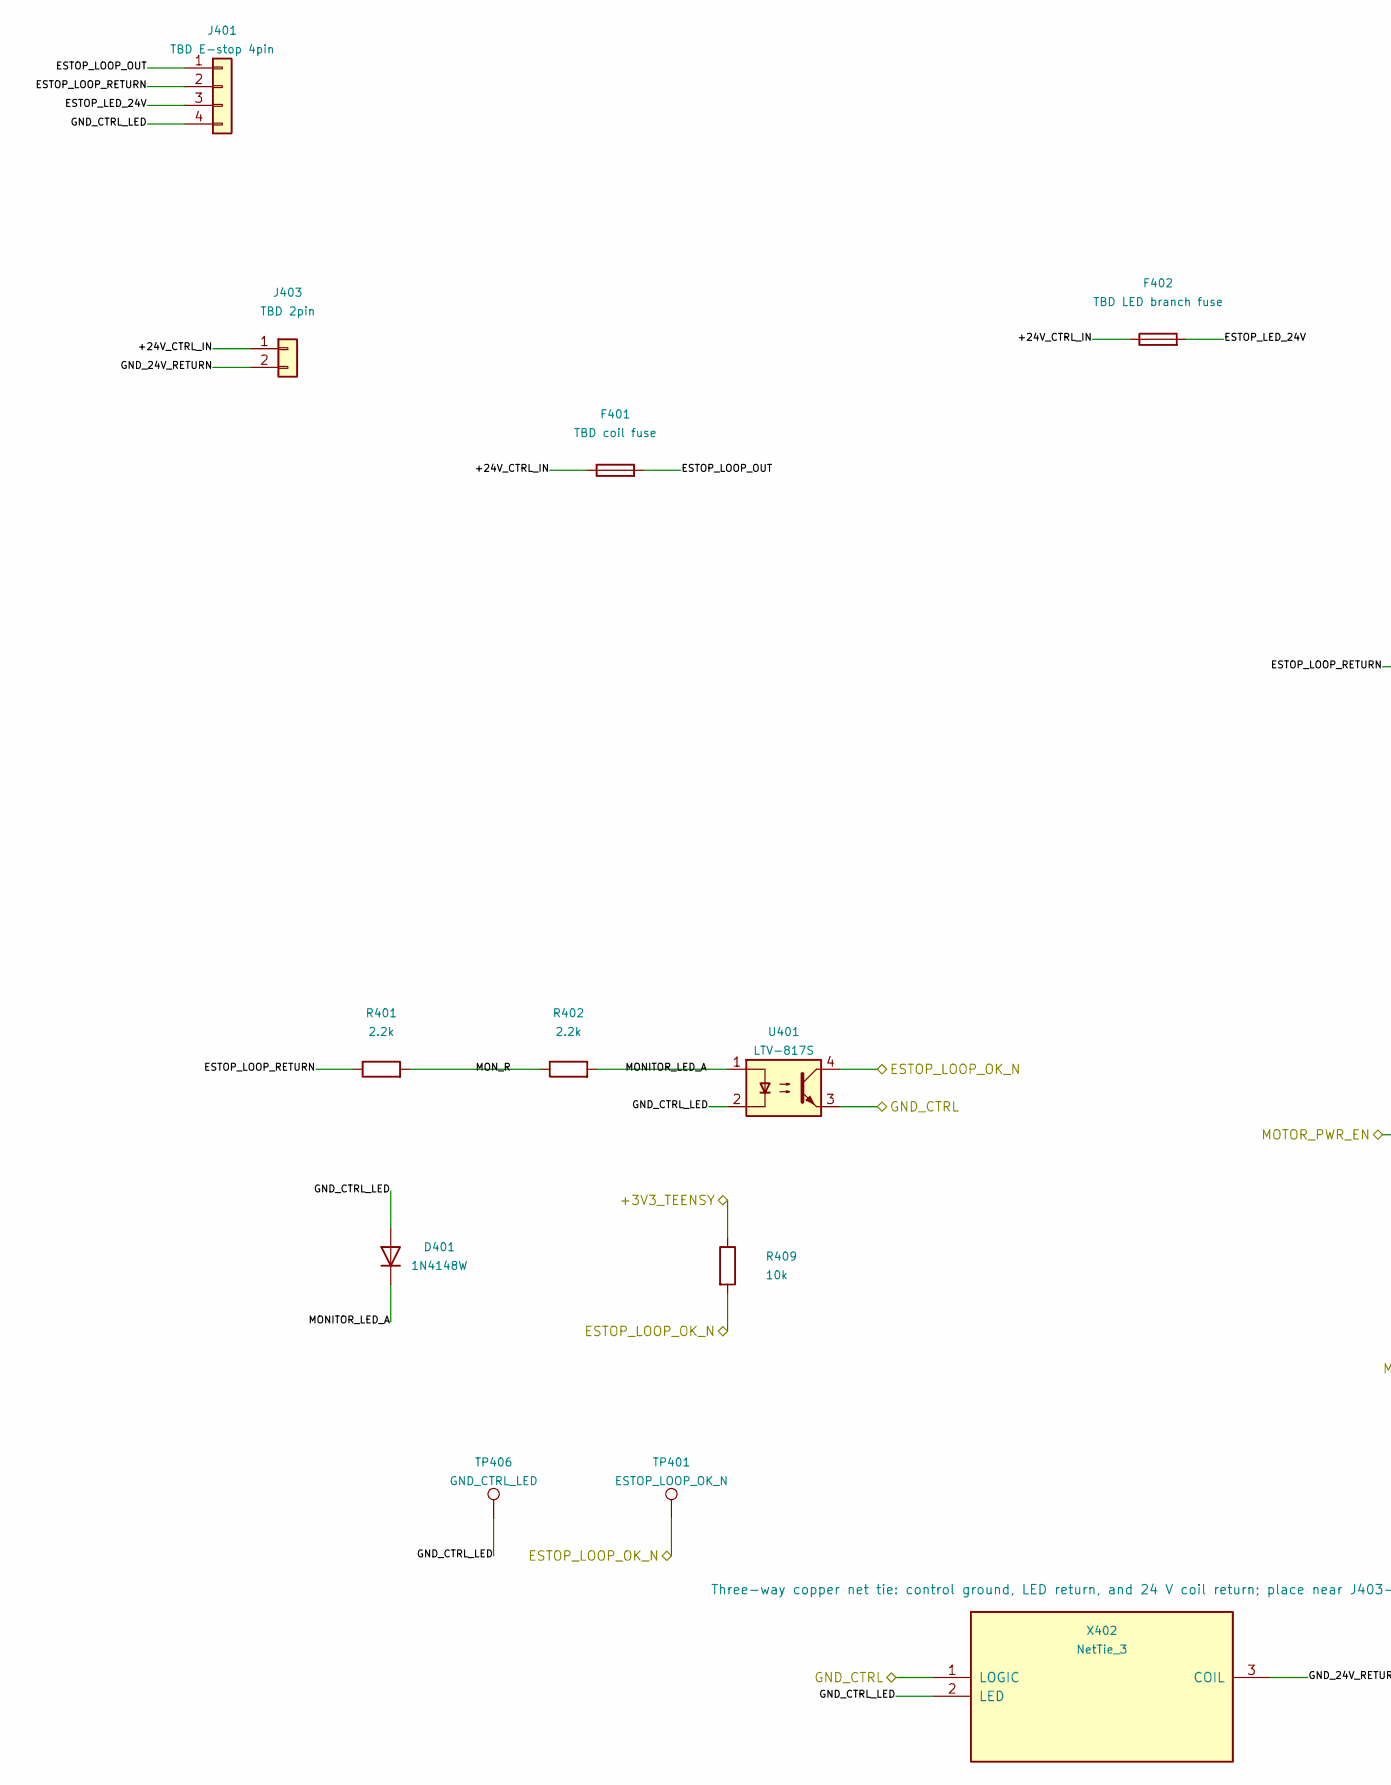
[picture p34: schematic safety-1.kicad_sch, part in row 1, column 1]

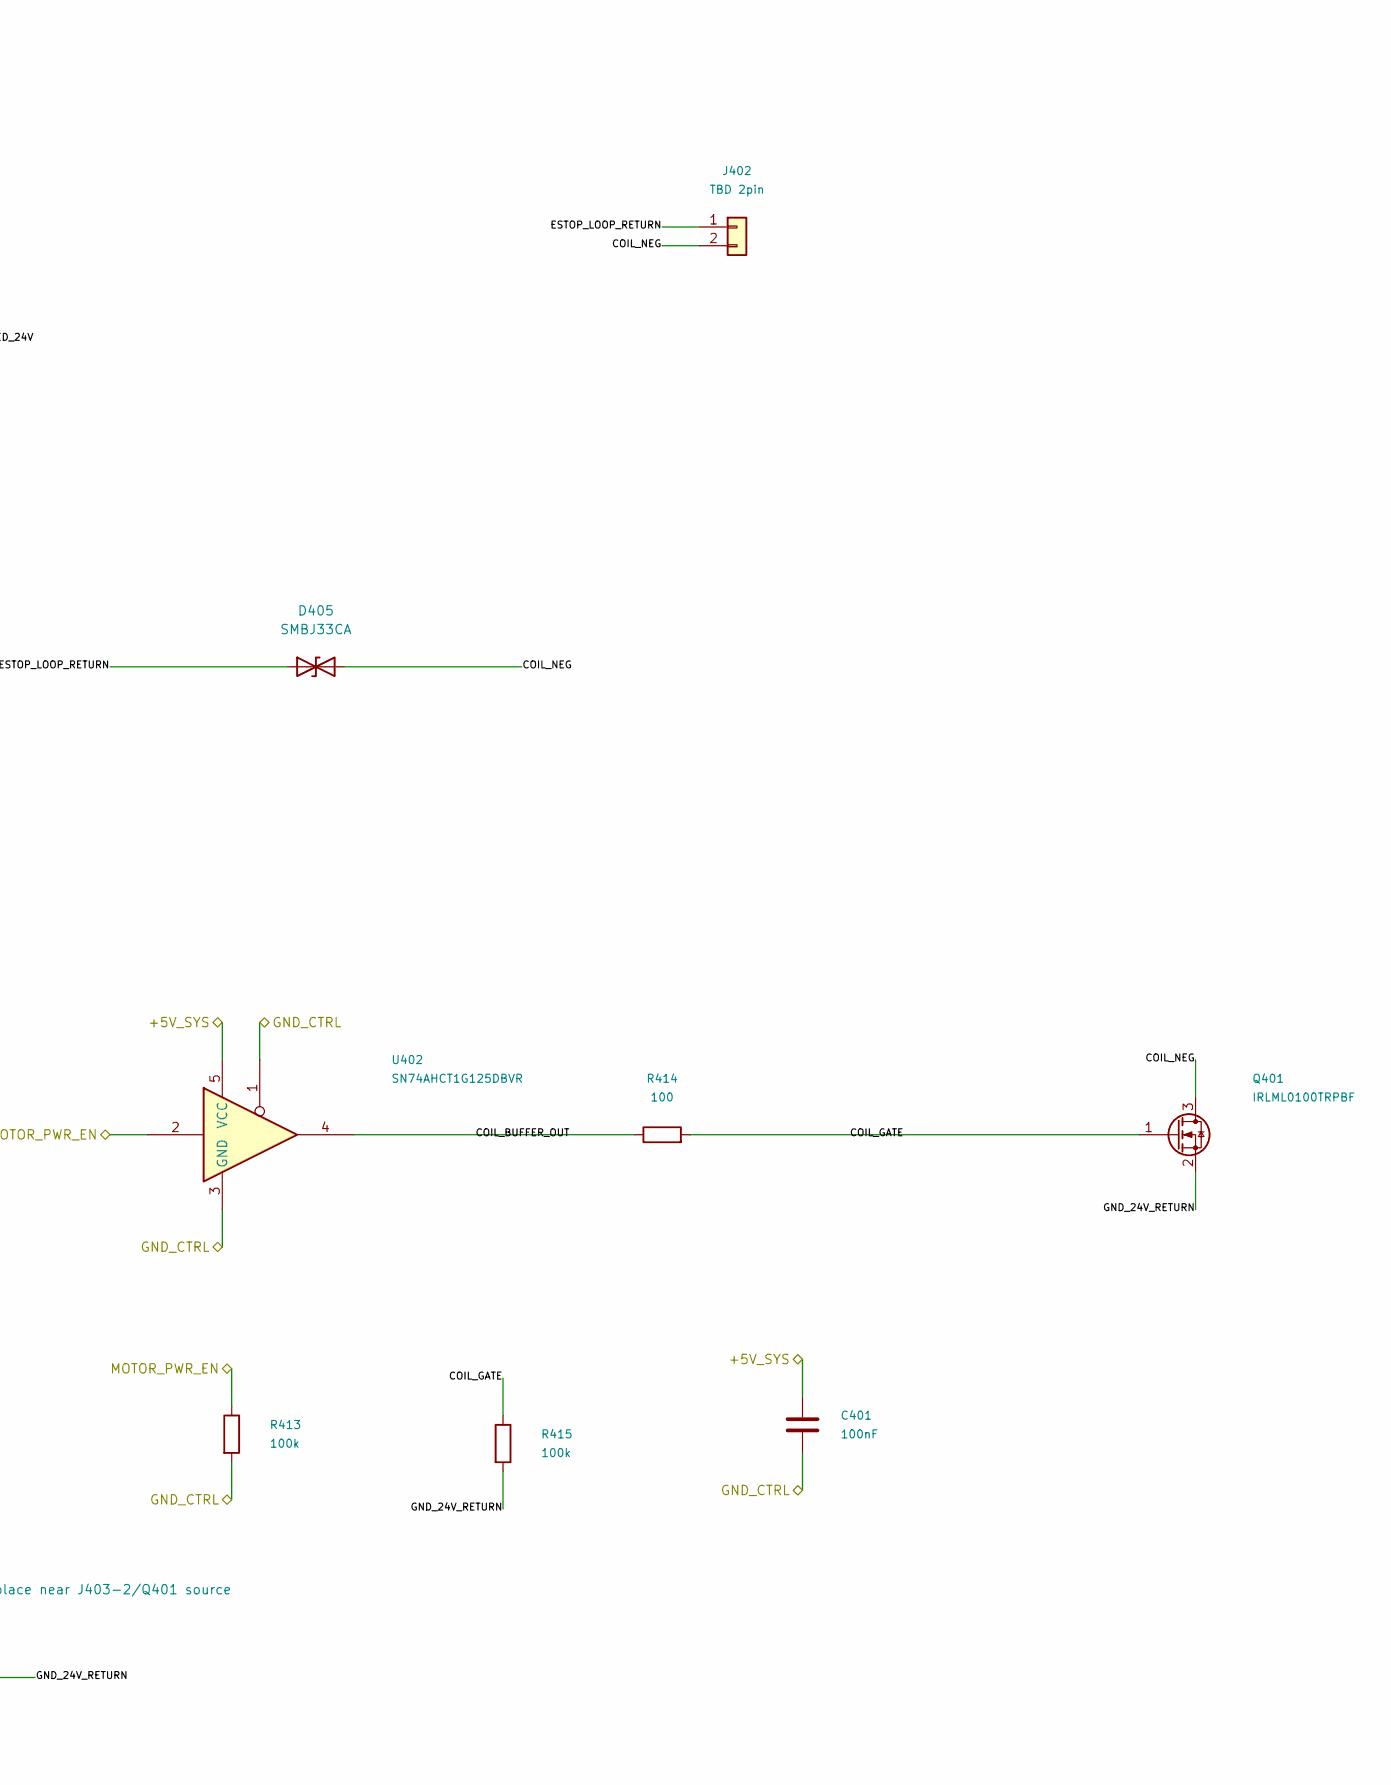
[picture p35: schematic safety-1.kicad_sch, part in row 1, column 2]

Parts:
C401: 100nF; C_0603_1608Metric
D401: 1N4148W; D_SOD-123
D405: SMBJ33CA; D_SMB; MPN SMBJ33CA
F401: TBD coil fuse
F402: TBD LED branch fuse
J401: TBD E-stop 4pin; JST_XH_S4B-XH-A_1x04_P2.50mm_Horizontal
J402: TBD 2pin
J403: TBD 2pin; JST_XH_S2B-XH-A_1x02_P2.50mm_Horizontal
Q401: IRLML0100TRPBF; SOT-23
R401, R402: 2.2k; R_0603_1608Metric
R409: 10k; R_0603_1608Metric
R413, R415: 100k; R_0603_1608Metric
R414: 100; R_0603_1608Metric
TP401: ESTOP_LOOP_OK_N; TestPoint_Pad_D1.5mm
TP406: GND_CTRL_LED; TestPoint_Pad_D1.5mm
U401: LTV-817S; SMDIP-4_W9.53mm
U402: SN74AHCT1G125DBVR; SOT-23-5
X402: NetTie_3; NetTie-3_SMD_Pad2.0mm

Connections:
/+3V3_TEENSY: R409.1; also elsewhere on the board
/+5V_SYS: C401.1, U402.5 (VCC); also elsewhere on the board
/E-stop monitoring, central coil driver/+24V_CTRL_IN: F401.1, F402.1, J403.1
/E-stop monitoring, central coil driver/COIL_BUFFER_OUT: R414.1, U402.4
/E-stop monitoring, central coil driver/COIL_GATE: Q401.1 (G), R414.2, R415.1
/E-stop monitoring, central coil driver/COIL_NEG: D405.2 (A2), J402.2, Q401.3 (D)
/E-stop monitoring, central coil driver/ESTOP_LED_24V: F402.2, J401.3
/E-stop monitoring, central coil driver/ESTOP_LOOP_OUT: F401.2, J401.1
/E-stop monitoring, central coil driver/ESTOP_LOOP_RETURN: D405.1 (A1), J401.2, J402.1, R401.1
/E-stop monitoring, central coil driver/GND_24V_RETURN: J403.2, Q401.2 (S), R415.2, X402.3 (COIL)
/E-stop monitoring, central coil driver/GND_CTRL_LED: D401.2 (A), J401.4, TP406.1 (1_1), U401.2, X402.2 (LED)
/E-stop monitoring, central coil driver/MONITOR_LED_A: D401.1 (K), R402.2, U401.1
/E-stop monitoring, central coil driver/MON_R: R401.2, R402.1
/ESTOP_LOOP_OK_N: R409.2, TP401.1 (1_1), U401.4; also elsewhere on the board
/MOTOR_PWR_EN: R413.1, U402.2; also elsewhere on the board
GND_CTRL: C401.2, R413.2, U401.3, U402.1, U402.3 (GND), X402.1 (LOGIC); also elsewhere on the board

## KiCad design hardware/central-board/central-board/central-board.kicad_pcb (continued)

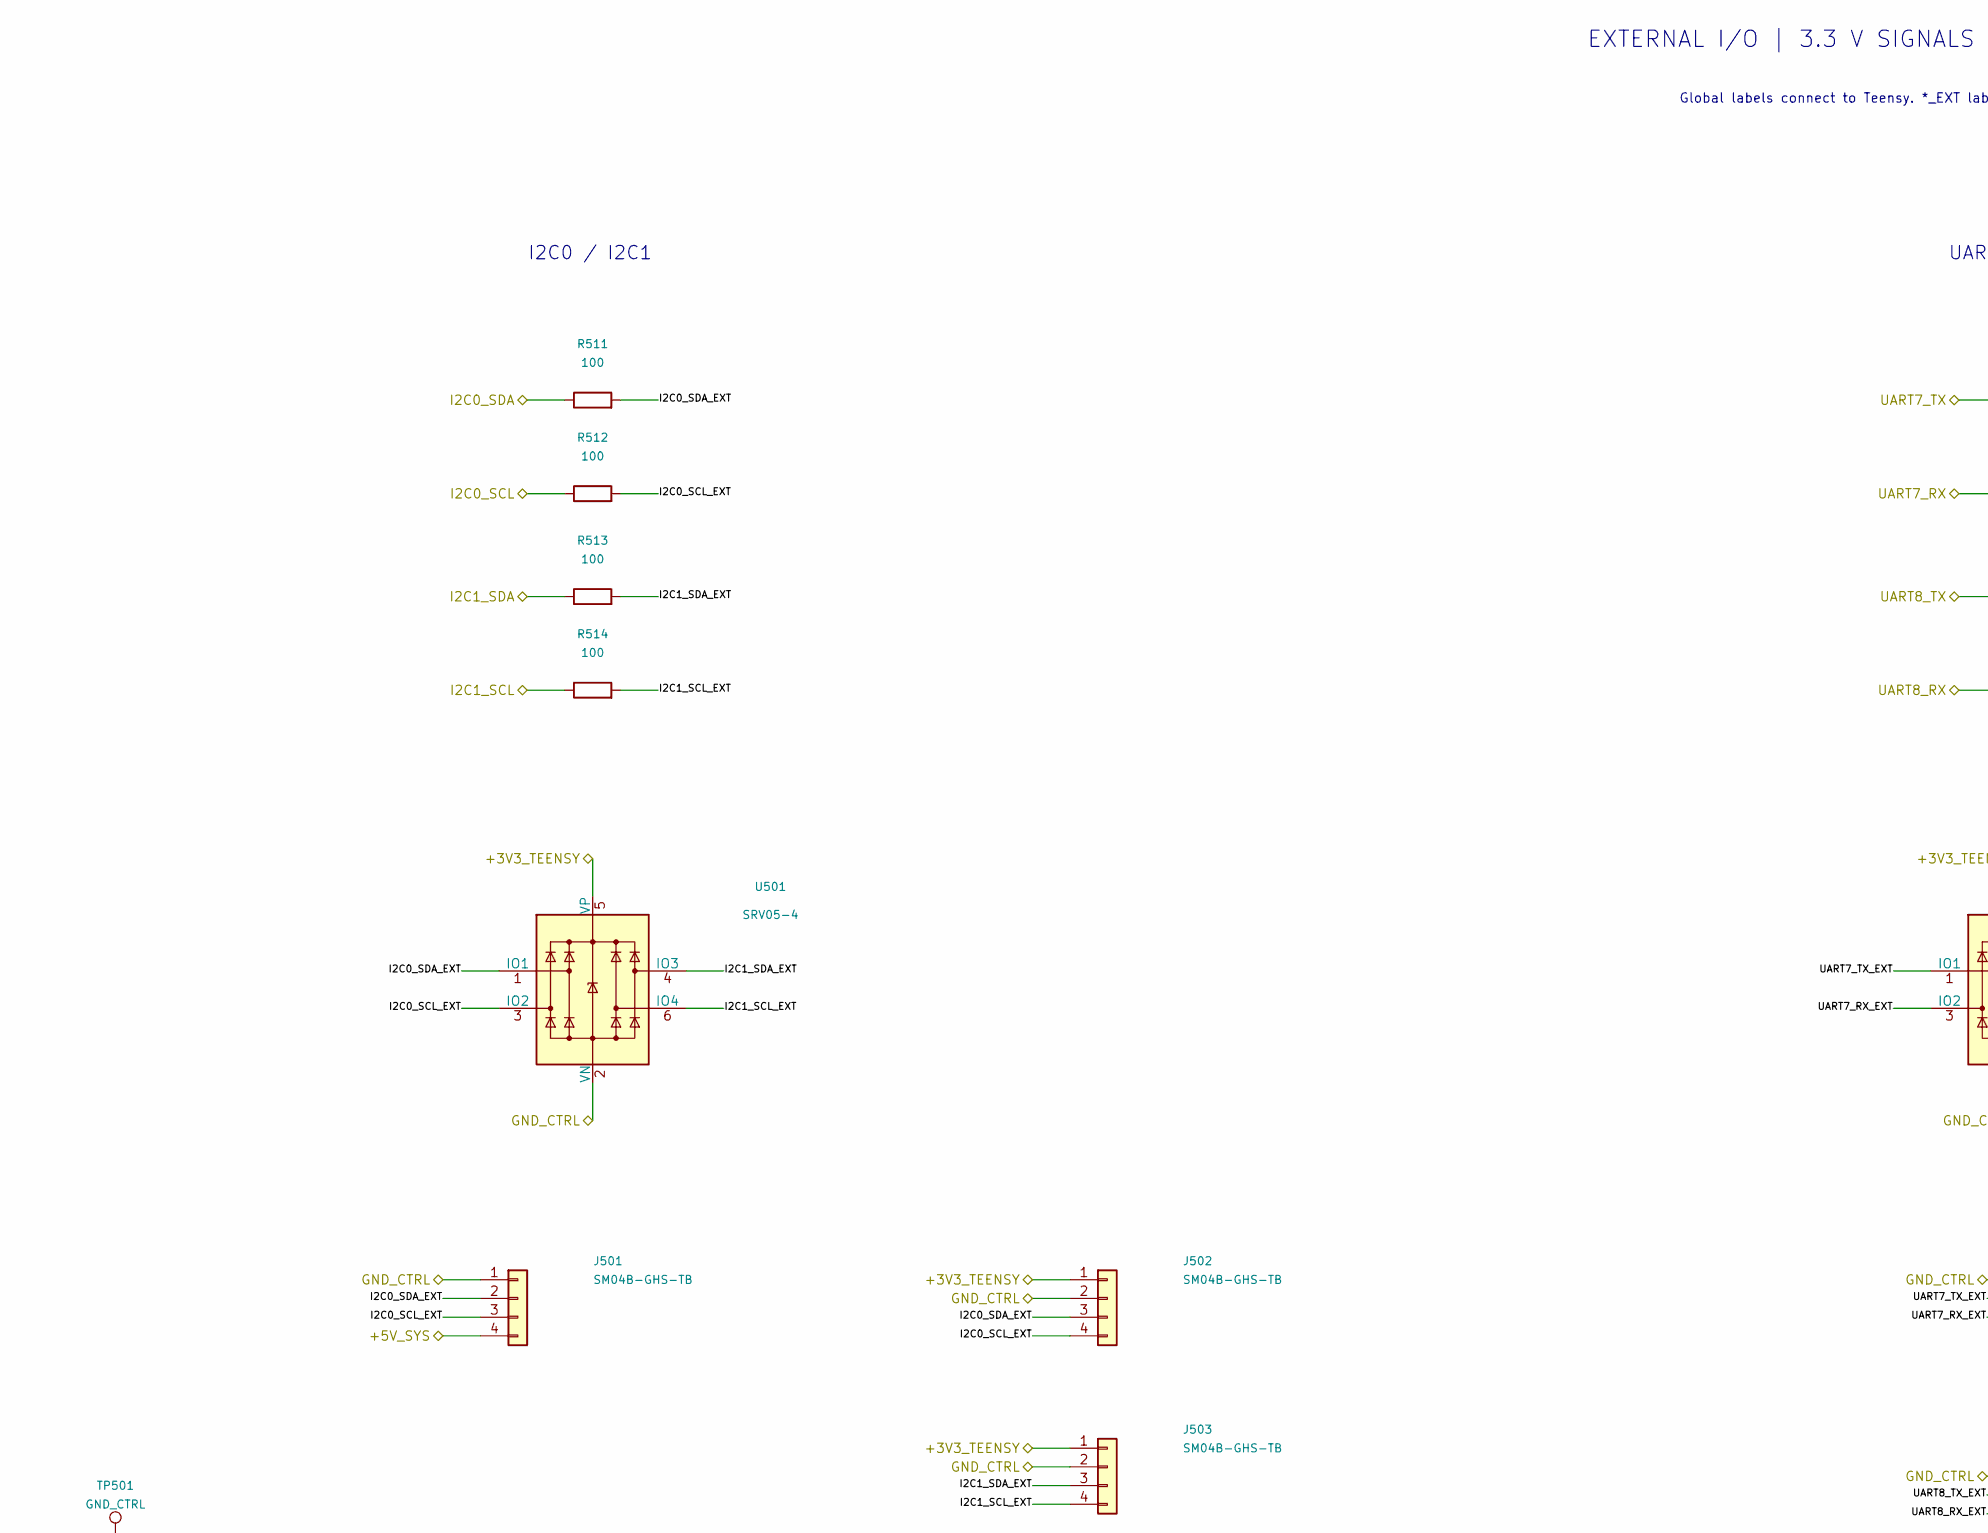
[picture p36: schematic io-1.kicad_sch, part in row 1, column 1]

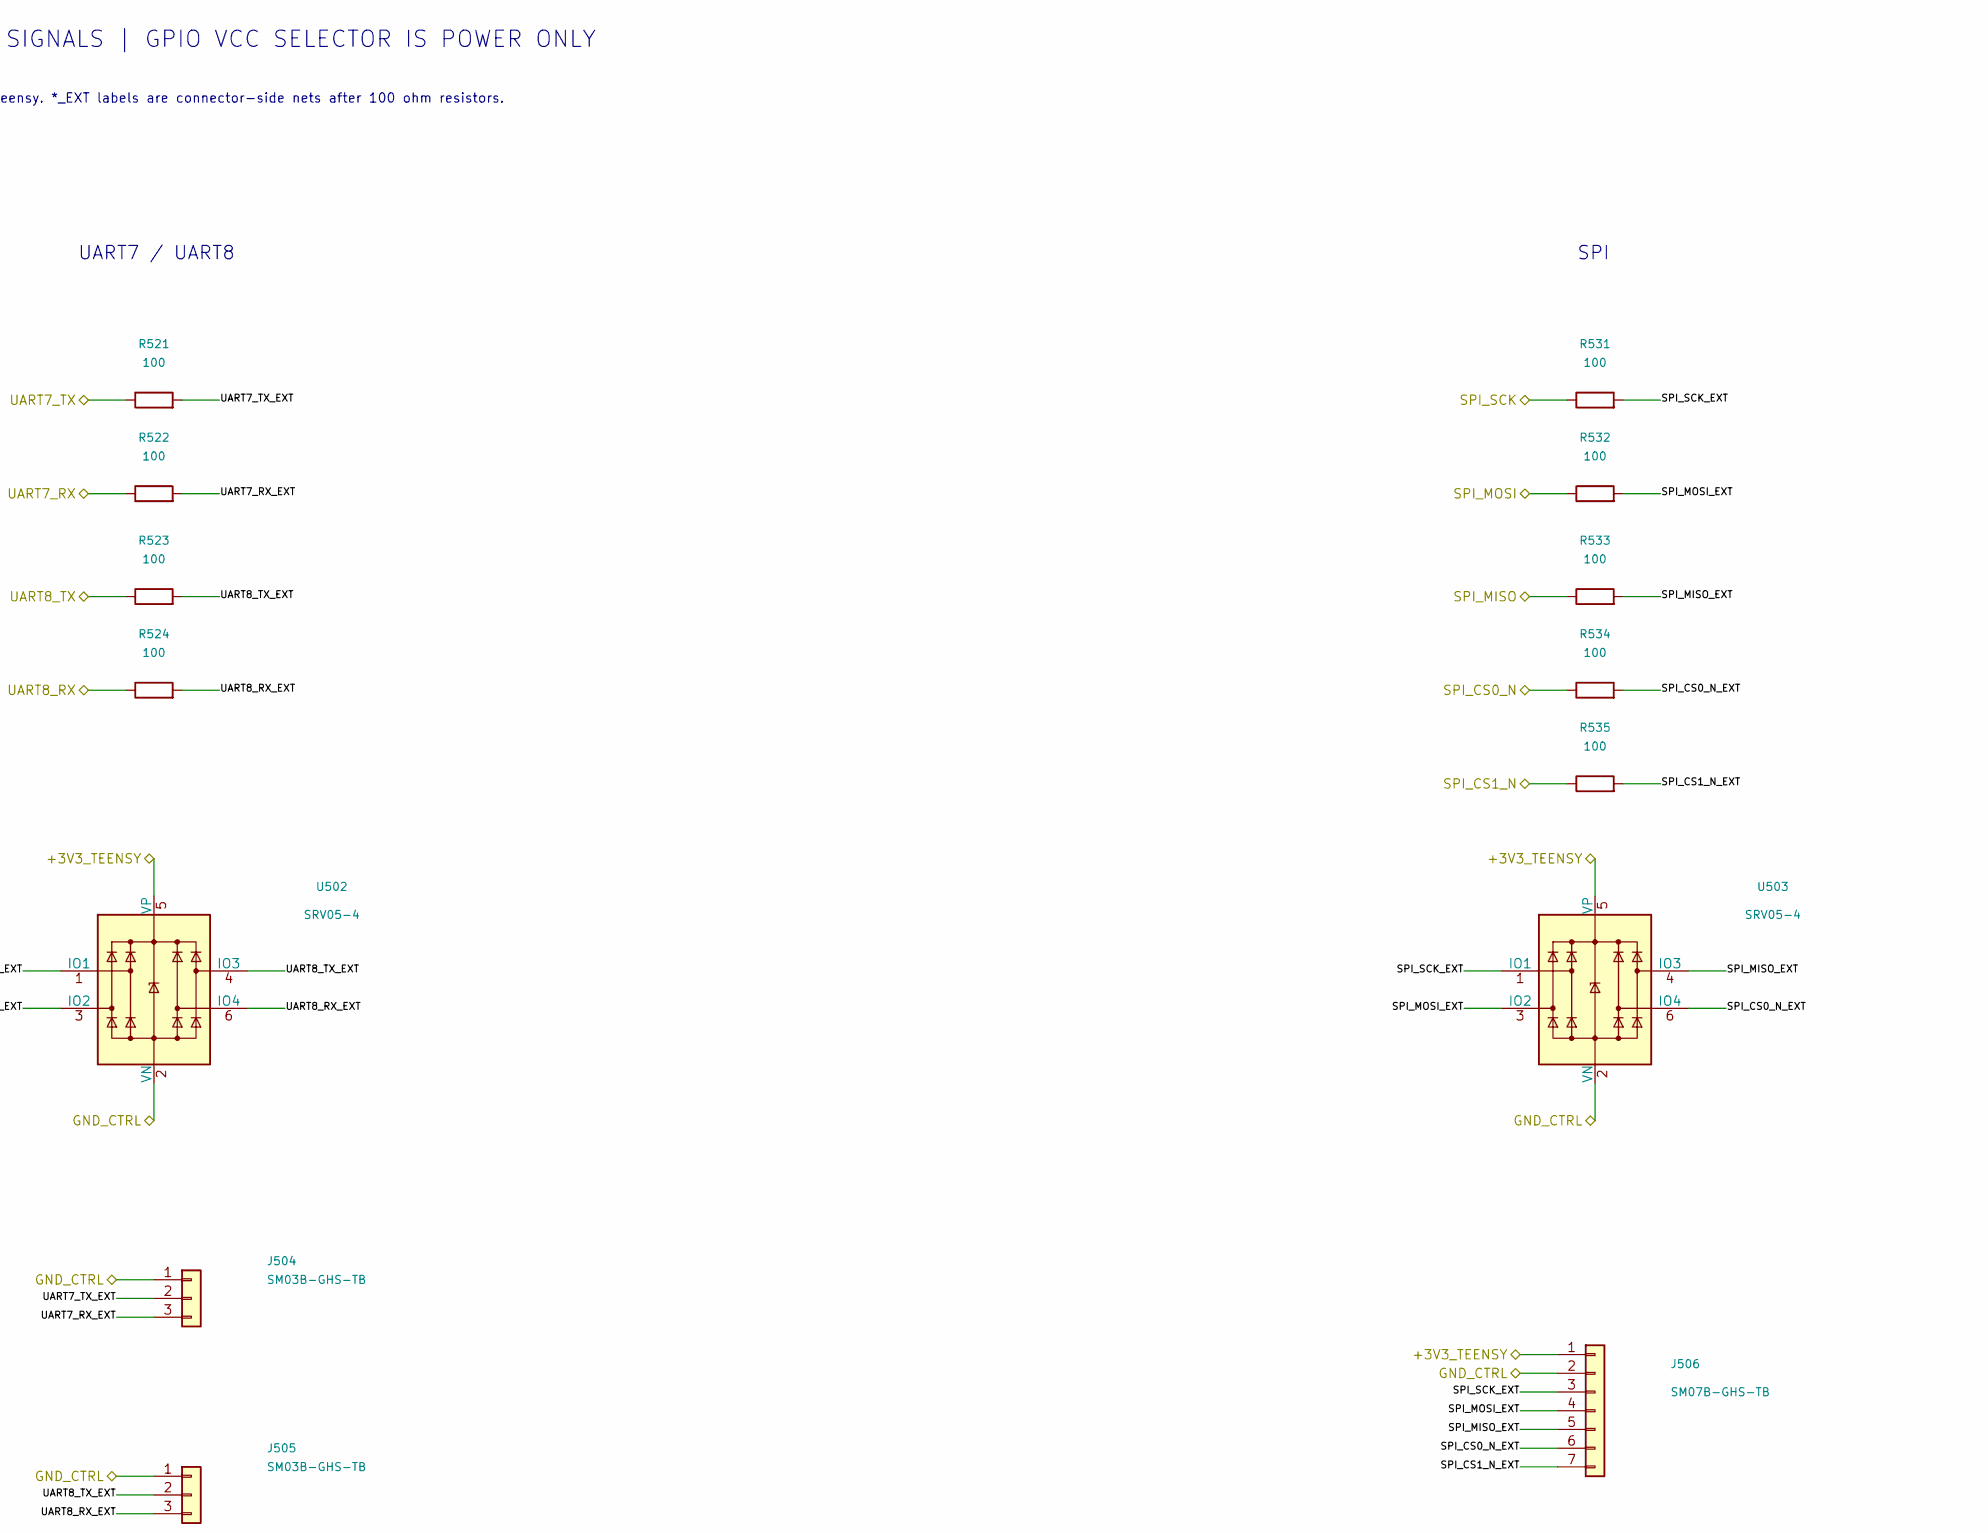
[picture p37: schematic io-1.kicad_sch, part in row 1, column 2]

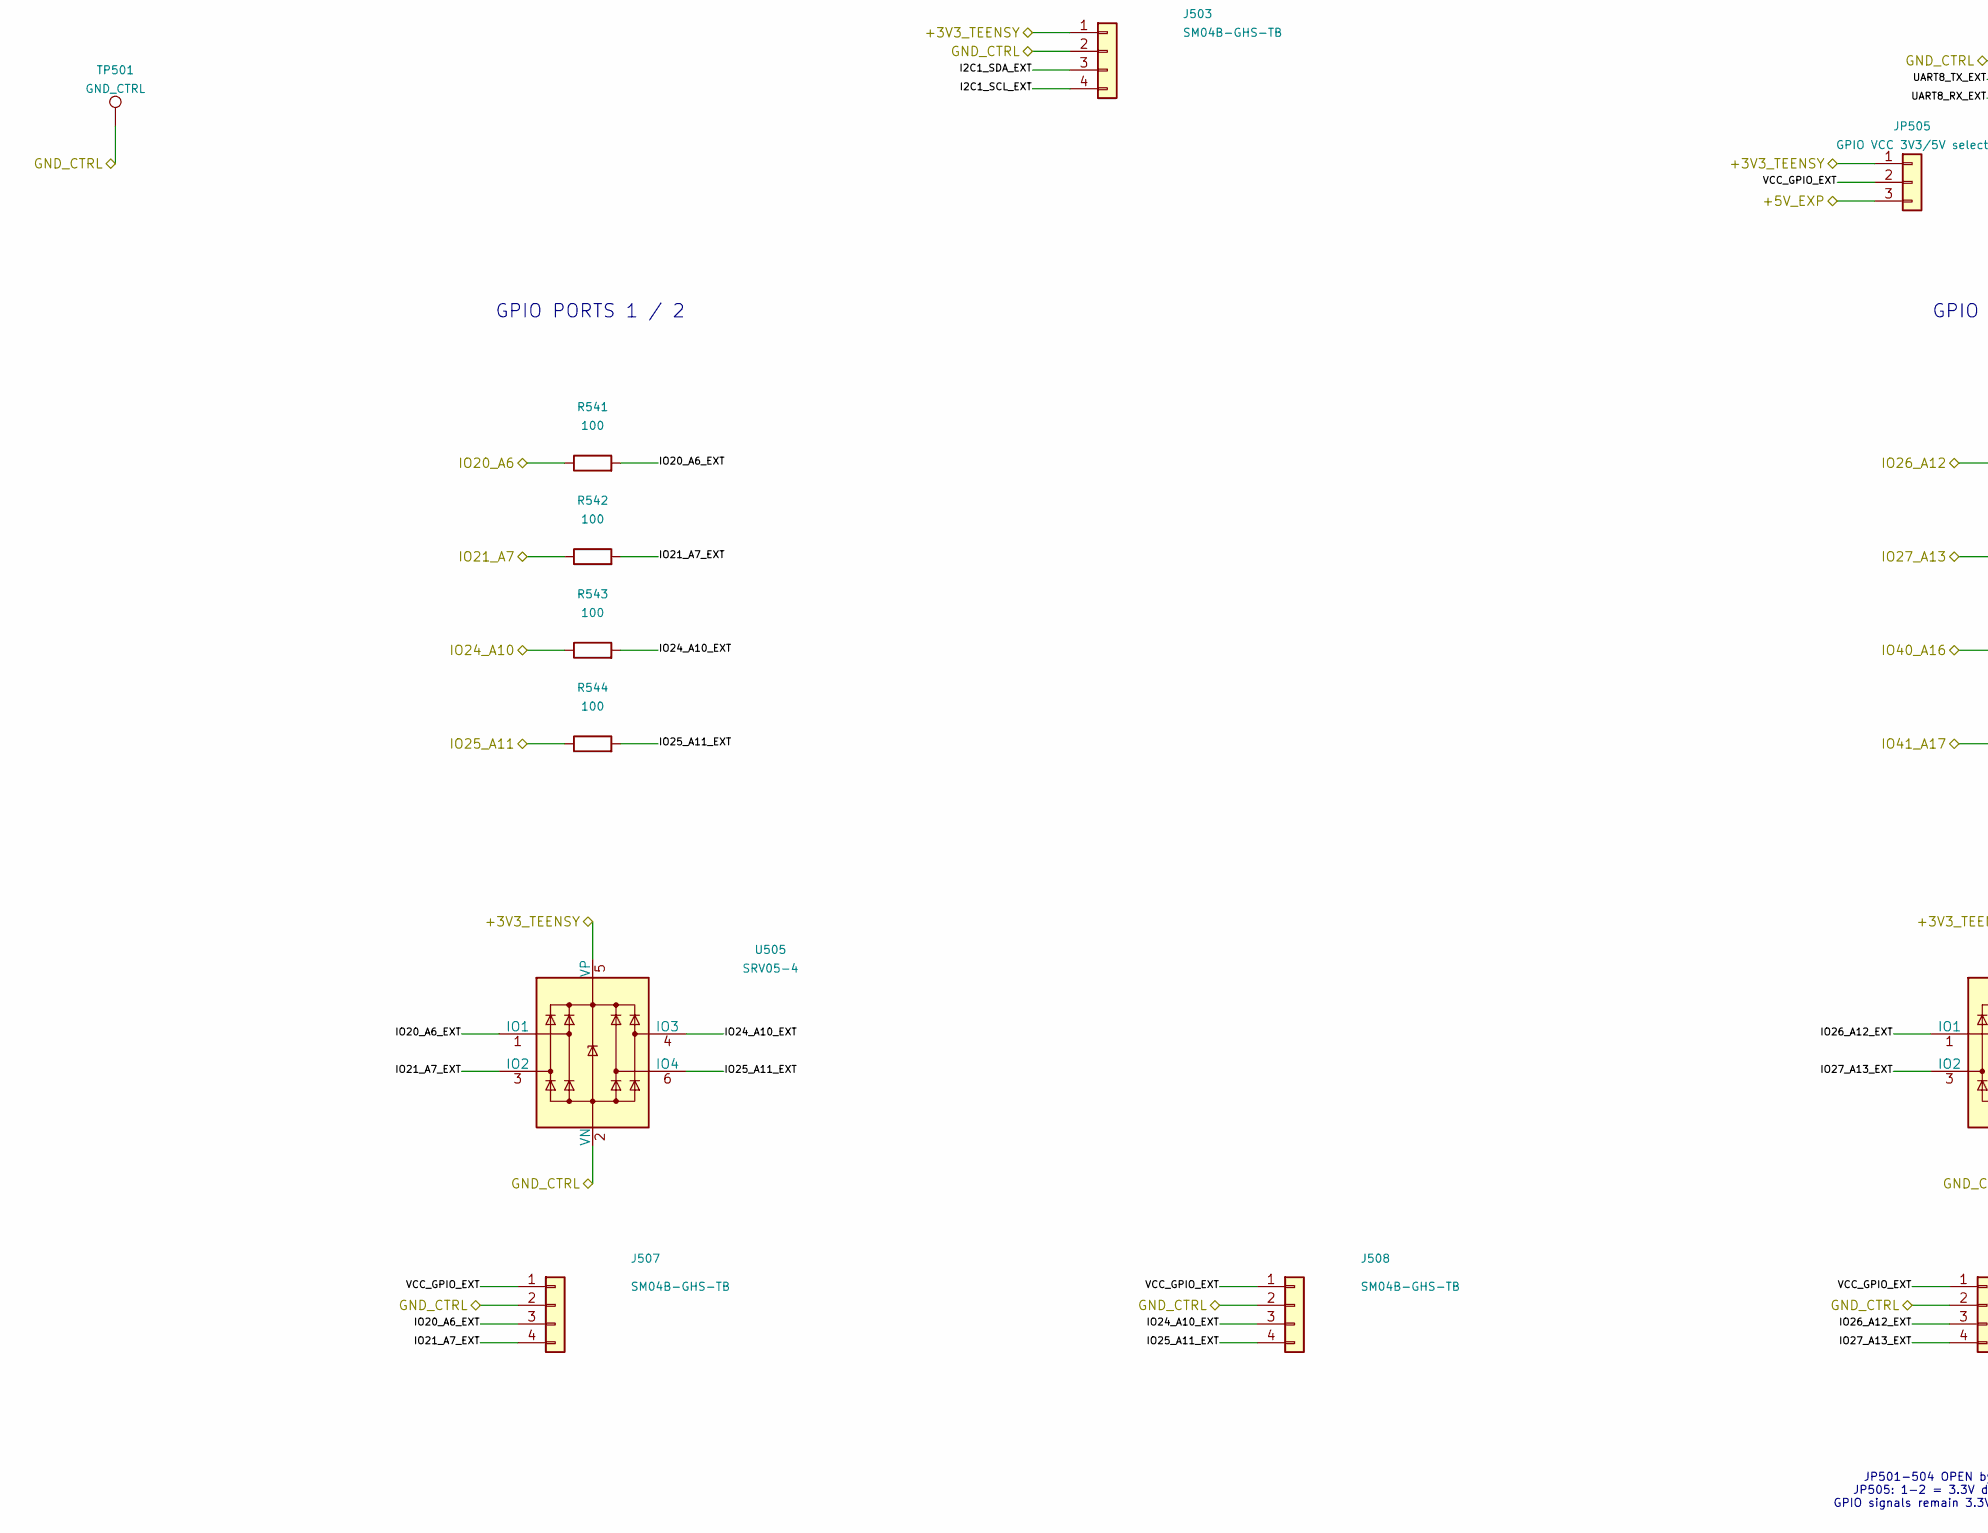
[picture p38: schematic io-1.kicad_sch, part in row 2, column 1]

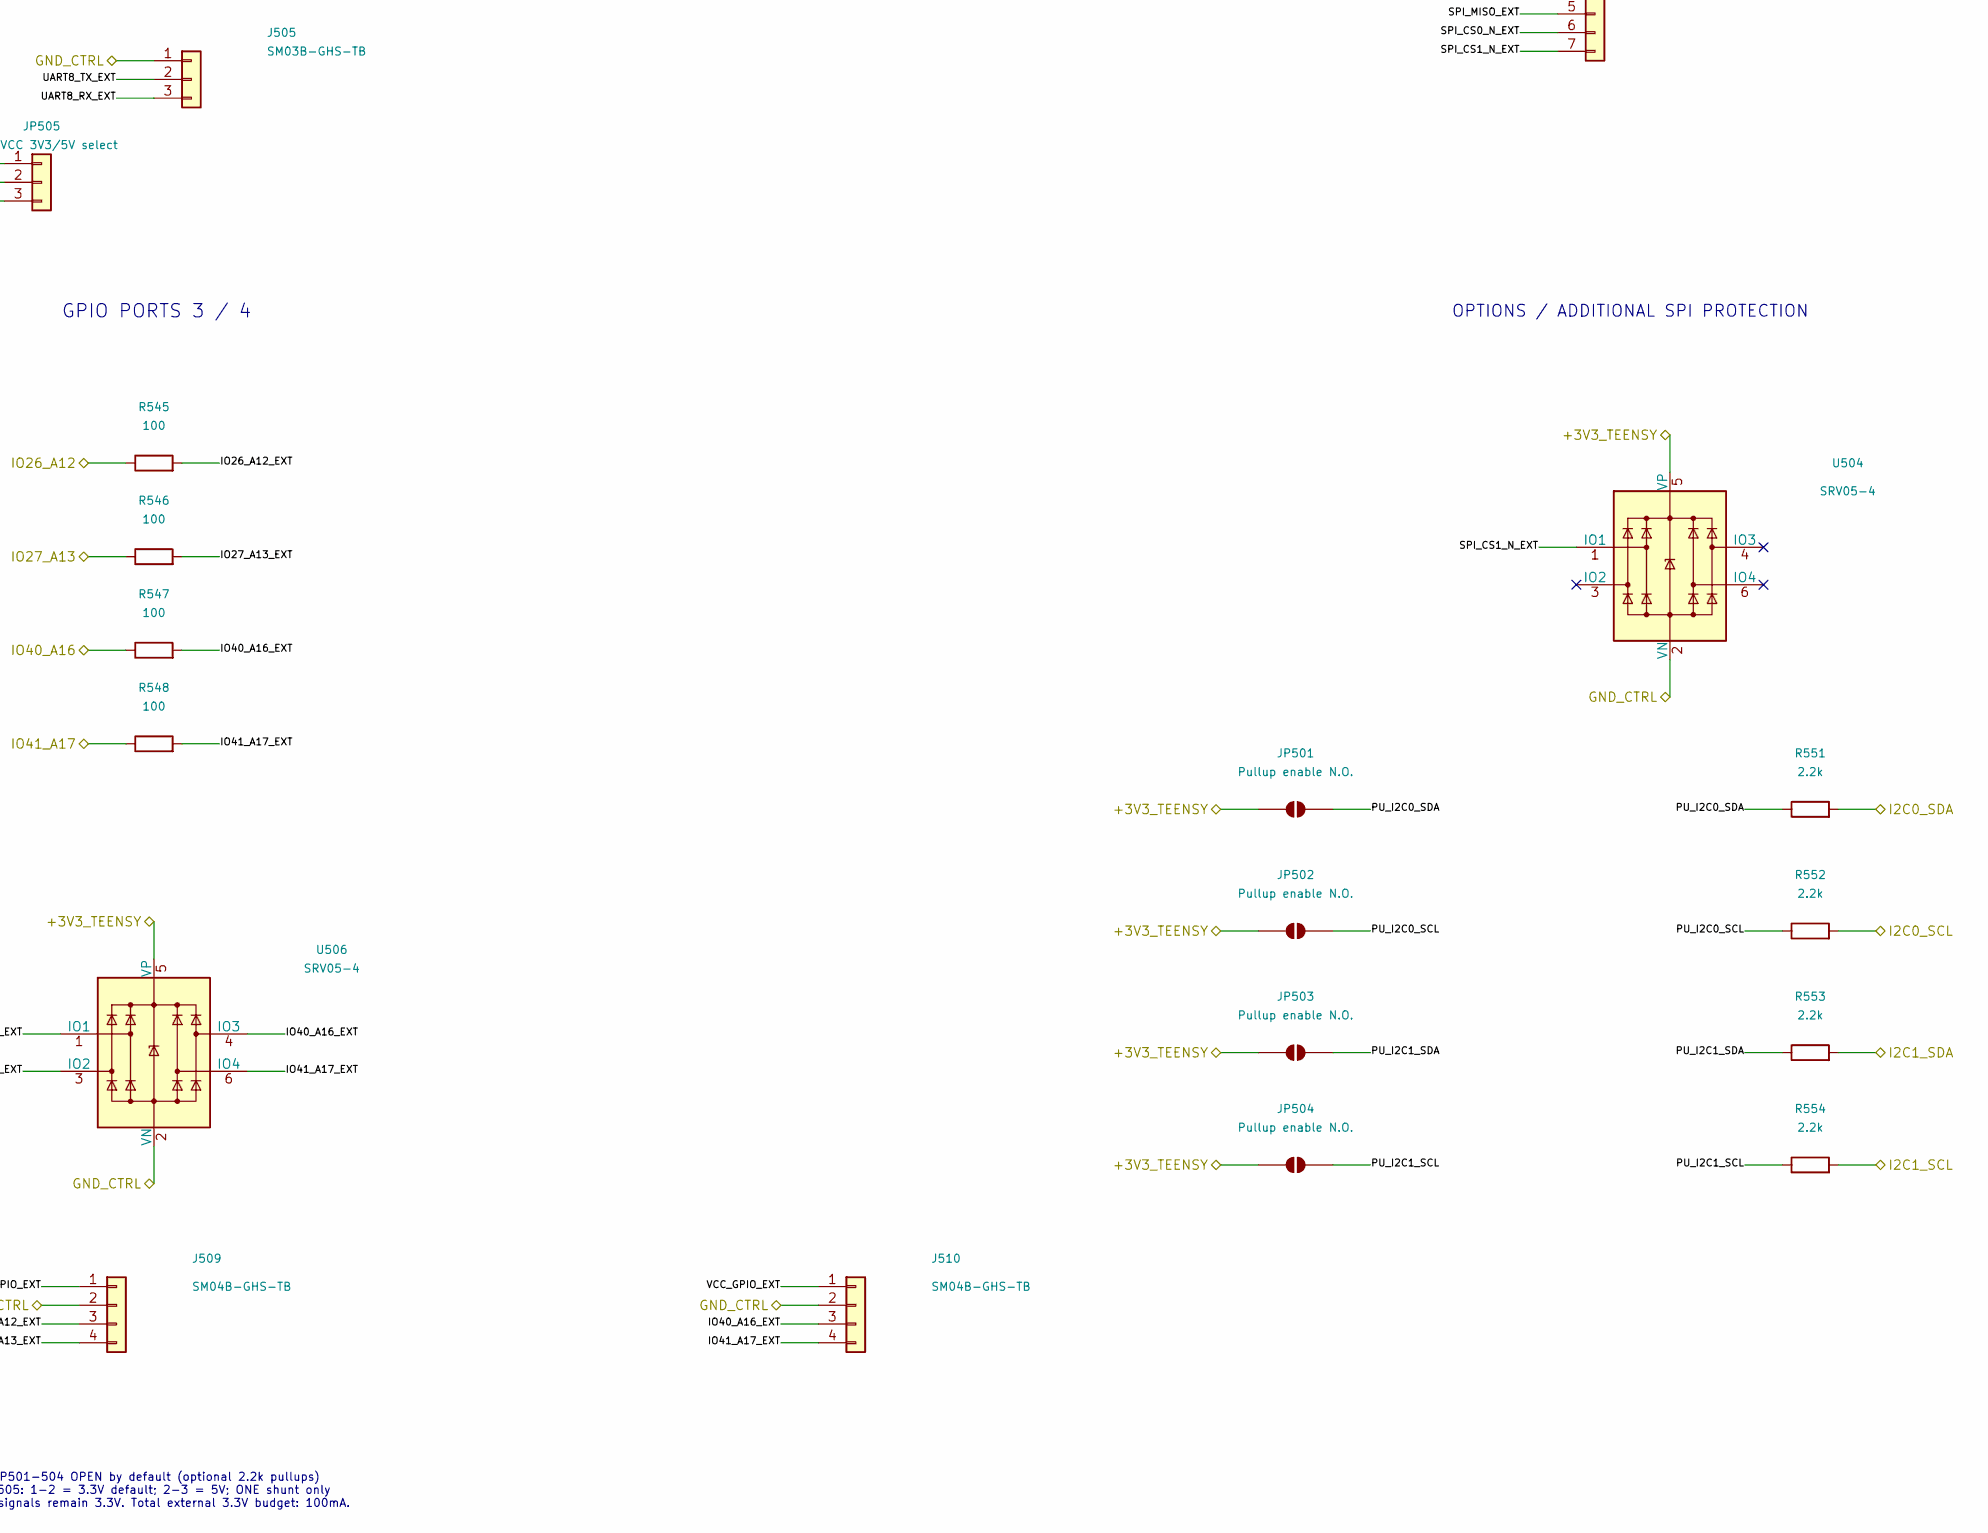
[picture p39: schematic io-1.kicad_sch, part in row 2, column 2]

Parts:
J501, J502, J503, J507, J508, J509, J510: SM04B-GHS-TB; JST_GH_SM04B-GHS-TB_1x04-1MP_P1.25mm_Horizontal
J504, J505: SM03B-GHS-TB; JST_GH_SM03B-GHS-TB_1x03-1MP_P1.25mm_Horizontal
J506: SM07B-GHS-TB; JST_GH_SM07B-GHS-TB_1x07-1MP_P1.25mm_Horizontal
JP501, JP502, JP503, JP504: Pullup enable N.O.; SolderJumper-2_P1.3mm_Open_RoundedPad1.0x1.5mm
JP505: GPIO VCC 3V3/5V select; PinHeader_1x03_P2.54mm_Vertical
R511, R512, R513, R514, R521, R522, R523, R524, R531, R532, R533, R534, R535, R541, R542, R543, R544, R545, R546, R547, R548: 100; R_0603_1608Metric
R551, R552, R553, R554: 2.2k; R_0603_1608Metric
TP501: GND_CTRL; Harwin_S1751-46R
U501, U502, U503, U504, U505, U506: SRV05-4; SOT-23-6

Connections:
/+3V3_TEENSY: J502.1, J503.1, J506.1, JP501.1 (A), JP502.1 (A), JP503.1 (A), JP504.1 (A), JP505.1, U501.5 (VP), U502.5 (VP), U503.5 (VP), U504.5 (VP), U505.5 (VP), U506.5 (VP); also elsewhere on the board
/+5V_EXP: JP505.3; also elsewhere on the board
/+5V_SYS: J501.4; also elsewhere on the board
/I2C0_SCL: R512.1, R552.2; also elsewhere on the board
/I2C0_SDA: R511.1, R551.2; also elsewhere on the board
/I2C1_SCL: R514.1, R554.2; also elsewhere on the board
/I2C1_SDA: R513.1, R553.2; also elsewhere on the board
/IO20_A6: R541.1; also elsewhere on the board
/IO21_A7: R542.1; also elsewhere on the board
/IO24_A10: R543.1; also elsewhere on the board
/IO25_A11: R544.1; also elsewhere on the board
/IO26_A12: R545.1; also elsewhere on the board
/IO27_A13: R546.1; also elsewhere on the board
/IO40_A16: R547.1; also elsewhere on the board
/IO41_A17: R548.1; also elsewhere on the board
/Matek battery monitor / expansion I/O (1)/I2C0_SCL_EXT: J501.3, J502.4, R512.2, U501.3 (IO2)
/Matek battery monitor / expansion I/O (1)/I2C0_SDA_EXT: J501.2, J502.3, R511.2, U501.1 (IO1)
/Matek battery monitor / expansion I/O (1)/I2C1_SCL_EXT: J503.4, R514.2, U501.6 (IO4)
/Matek battery monitor / expansion I/O (1)/I2C1_SDA_EXT: J503.3, R513.2, U501.4 (IO3)
/Matek battery monitor / expansion I/O (1)/IO20_A6_EXT: J507.3, R541.2, U505.1 (IO1)
/Matek battery monitor / expansion I/O (1)/IO21_A7_EXT: J507.4, R542.2, U505.3 (IO2)
/Matek battery monitor / expansion I/O (1)/IO24_A10_EXT: J508.3, R543.2, U505.4 (IO3)
/Matek battery monitor / expansion I/O (1)/IO25_A11_EXT: J508.4, R544.2, U505.6 (IO4)
/Matek battery monitor / expansion I/O (1)/IO26_A12_EXT: J509.3, R545.2, U506.1 (IO1)
/Matek battery monitor / expansion I/O (1)/IO27_A13_EXT: J509.4, R546.2, U506.3 (IO2)
/Matek battery monitor / expansion I/O (1)/IO40_A16_EXT: J510.3, R547.2, U506.4 (IO3)
/Matek battery monitor / expansion I/O (1)/IO41_A17_EXT: J510.4, R548.2, U506.6 (IO4)
/Matek battery monitor / expansion I/O (1)/PU_I2C0_SCL: JP502.2 (B), R552.1
/Matek battery monitor / expansion I/O (1)/PU_I2C0_SDA: JP501.2 (B), R551.1
/Matek battery monitor / expansion I/O (1)/PU_I2C1_SCL: JP504.2 (B), R554.1
/Matek battery monitor / expansion I/O (1)/PU_I2C1_SDA: JP503.2 (B), R553.1
/Matek battery monitor / expansion I/O (1)/SPI_CS0_N_EXT: J506.6, R534.2, U503.6 (IO4)
/Matek battery monitor / expansion I/O (1)/SPI_CS1_N_EXT: J506.7, R535.2, U504.1 (IO1)
/Matek battery monitor / expansion I/O (1)/SPI_MISO_EXT: J506.5, R533.2, U503.4 (IO3)
/Matek battery monitor / expansion I/O (1)/SPI_MOSI_EXT: J506.4, R532.2, U503.3 (IO2)
/Matek battery monitor / expansion I/O (1)/SPI_SCK_EXT: J506.3, R531.2, U503.1 (IO1)
/Matek battery monitor / expansion I/O (1)/UART7_RX_EXT: J504.3, R522.2, U502.3 (IO2)
/Matek battery monitor / expansion I/O (1)/UART7_TX_EXT: J504.2, R521.2, U502.1 (IO1)
/Matek battery monitor / expansion I/O (1)/UART8_RX_EXT: J505.3, R524.2, U502.6 (IO4)
/Matek battery monitor / expansion I/O (1)/UART8_TX_EXT: J505.2, R523.2, U502.4 (IO3)
/Matek battery monitor / expansion I/O (1)/VCC_GPIO_EXT: J507.1, J508.1, J509.1, J510.1, JP505.2
/SPI_CS0_N: R534.1; also elsewhere on the board
/SPI_CS1_N: R535.1; also elsewhere on the board
/SPI_MISO: R533.1; also elsewhere on the board
/SPI_MOSI: R532.1; also elsewhere on the board
/SPI_SCK: R531.1; also elsewhere on the board
/UART7_RX: R522.1; also elsewhere on the board
/UART7_TX: R521.1; also elsewhere on the board
/UART8_RX: R524.1; also elsewhere on the board
/UART8_TX: R523.1; also elsewhere on the board
GND_CTRL: J501.1, J502.2, J503.2, J504.1, J505.1, J506.2, J507.2, J508.2, J509.2, J510.2, TP501.1 (1_1), U501.2 (VN), U502.2 (VN), U503.2 (VN), U504.2 (VN), U505.2 (VN), U506.2 (VN); also elsewhere on the board

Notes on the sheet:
OPTIONS / ADDITIONAL SPI PROTECTION
UART7 / UART8
I2C0 / I2C1
JP501-504 OPEN by default (optional 2.2k pullups) JP505: 1-2 = 3.3V default; 2-3 = 5V; ONE shunt only GPIO signals remain 3.3V. Total external 3.3V budget: 100mA.
GPIO PORTS 3 / 4
SPI
GPIO PORTS 1 / 2
Global labels connect to Teensy. *_EXT labels are connector-side nets after 100 ohm resistors.
EXTERNAL I/O | 3.3 V SIGNALS | GPIO VCC SELECTOR IS POWER ONLY

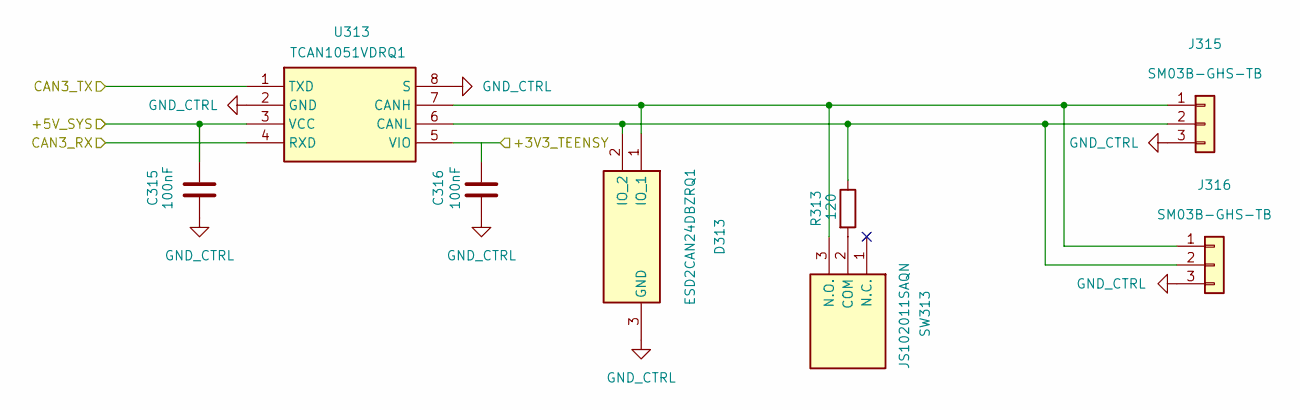
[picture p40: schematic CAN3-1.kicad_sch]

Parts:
C315, C316: 100nF; C_0603_1608Metric
D313: ESD2CAN24DBZRQ1; SOT-23
J315, J316: SM03B-GHS-TB; JST_GH_SM03B-GHS-TB_1x03-1MP_P1.25mm_Horizontal
R313: 120; R_0603_1608Metric
SW313: JS102011SAQN
U313: TCAN1051VDRQ1; SOIC-8_3.9x4.9mm_P1.27mm

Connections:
/+3V3_TEENSY: C316.1, U313.5 (VIO); also elsewhere on the board
/+5V_SYS: C315.1, U313.3 (VCC); also elsewhere on the board
/CAN3_RX: U313.4 (RXD); also elsewhere on the board
/CAN3_TX: U313.1 (TXD); also elsewhere on the board
GND_CTRL: C315.2, C316.2, D313.3 (GND), J315.3, J316.3, U313.2 (GND), U313.8 (S); also elsewhere on the board
unnamed: D313.1 (IO_1), J315.1, J316.1, SW313.3 (N.O.), U313.7 (CANH)
unnamed: D313.2 (IO_2), J315.2, J316.2, R313.1, U313.6 (CANL)
unnamed: R313.2, SW313.2 (COM)

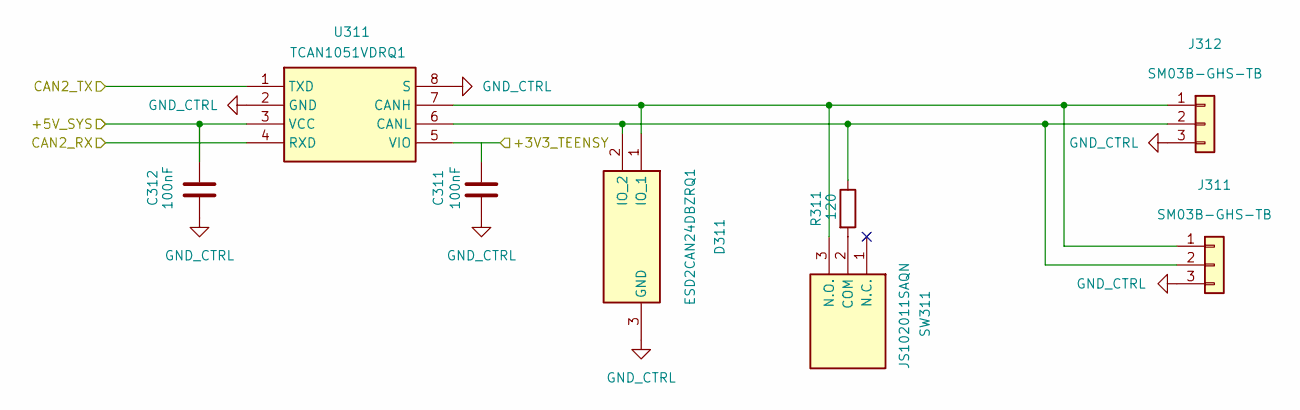
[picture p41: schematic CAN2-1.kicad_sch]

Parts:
C311, C312: 100nF; C_0603_1608Metric
D311: ESD2CAN24DBZRQ1; SOT-23
J311, J312: SM03B-GHS-TB; JST_GH_SM03B-GHS-TB_1x03-1MP_P1.25mm_Horizontal
R311: 120; R_0603_1608Metric
SW311: JS102011SAQN
U311: TCAN1051VDRQ1; SOIC-8_3.9x4.9mm_P1.27mm

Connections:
/+3V3_TEENSY: C311.1, U311.5 (VIO); also elsewhere on the board
/+5V_SYS: C312.1, U311.3 (VCC); also elsewhere on the board
/CAN2_RX: U311.4 (RXD); also elsewhere on the board
/CAN2_TX: U311.1 (TXD); also elsewhere on the board
GND_CTRL: C311.2, C312.2, D311.3 (GND), J311.3, J312.3, U311.2 (GND), U311.8 (S); also elsewhere on the board
unnamed: D311.1 (IO_1), J311.1, J312.1, SW311.3 (N.O.), U311.7 (CANH)
unnamed: D311.2 (IO_2), J311.2, J312.2, R311.1, U311.6 (CANL)
unnamed: R311.2, SW311.2 (COM)

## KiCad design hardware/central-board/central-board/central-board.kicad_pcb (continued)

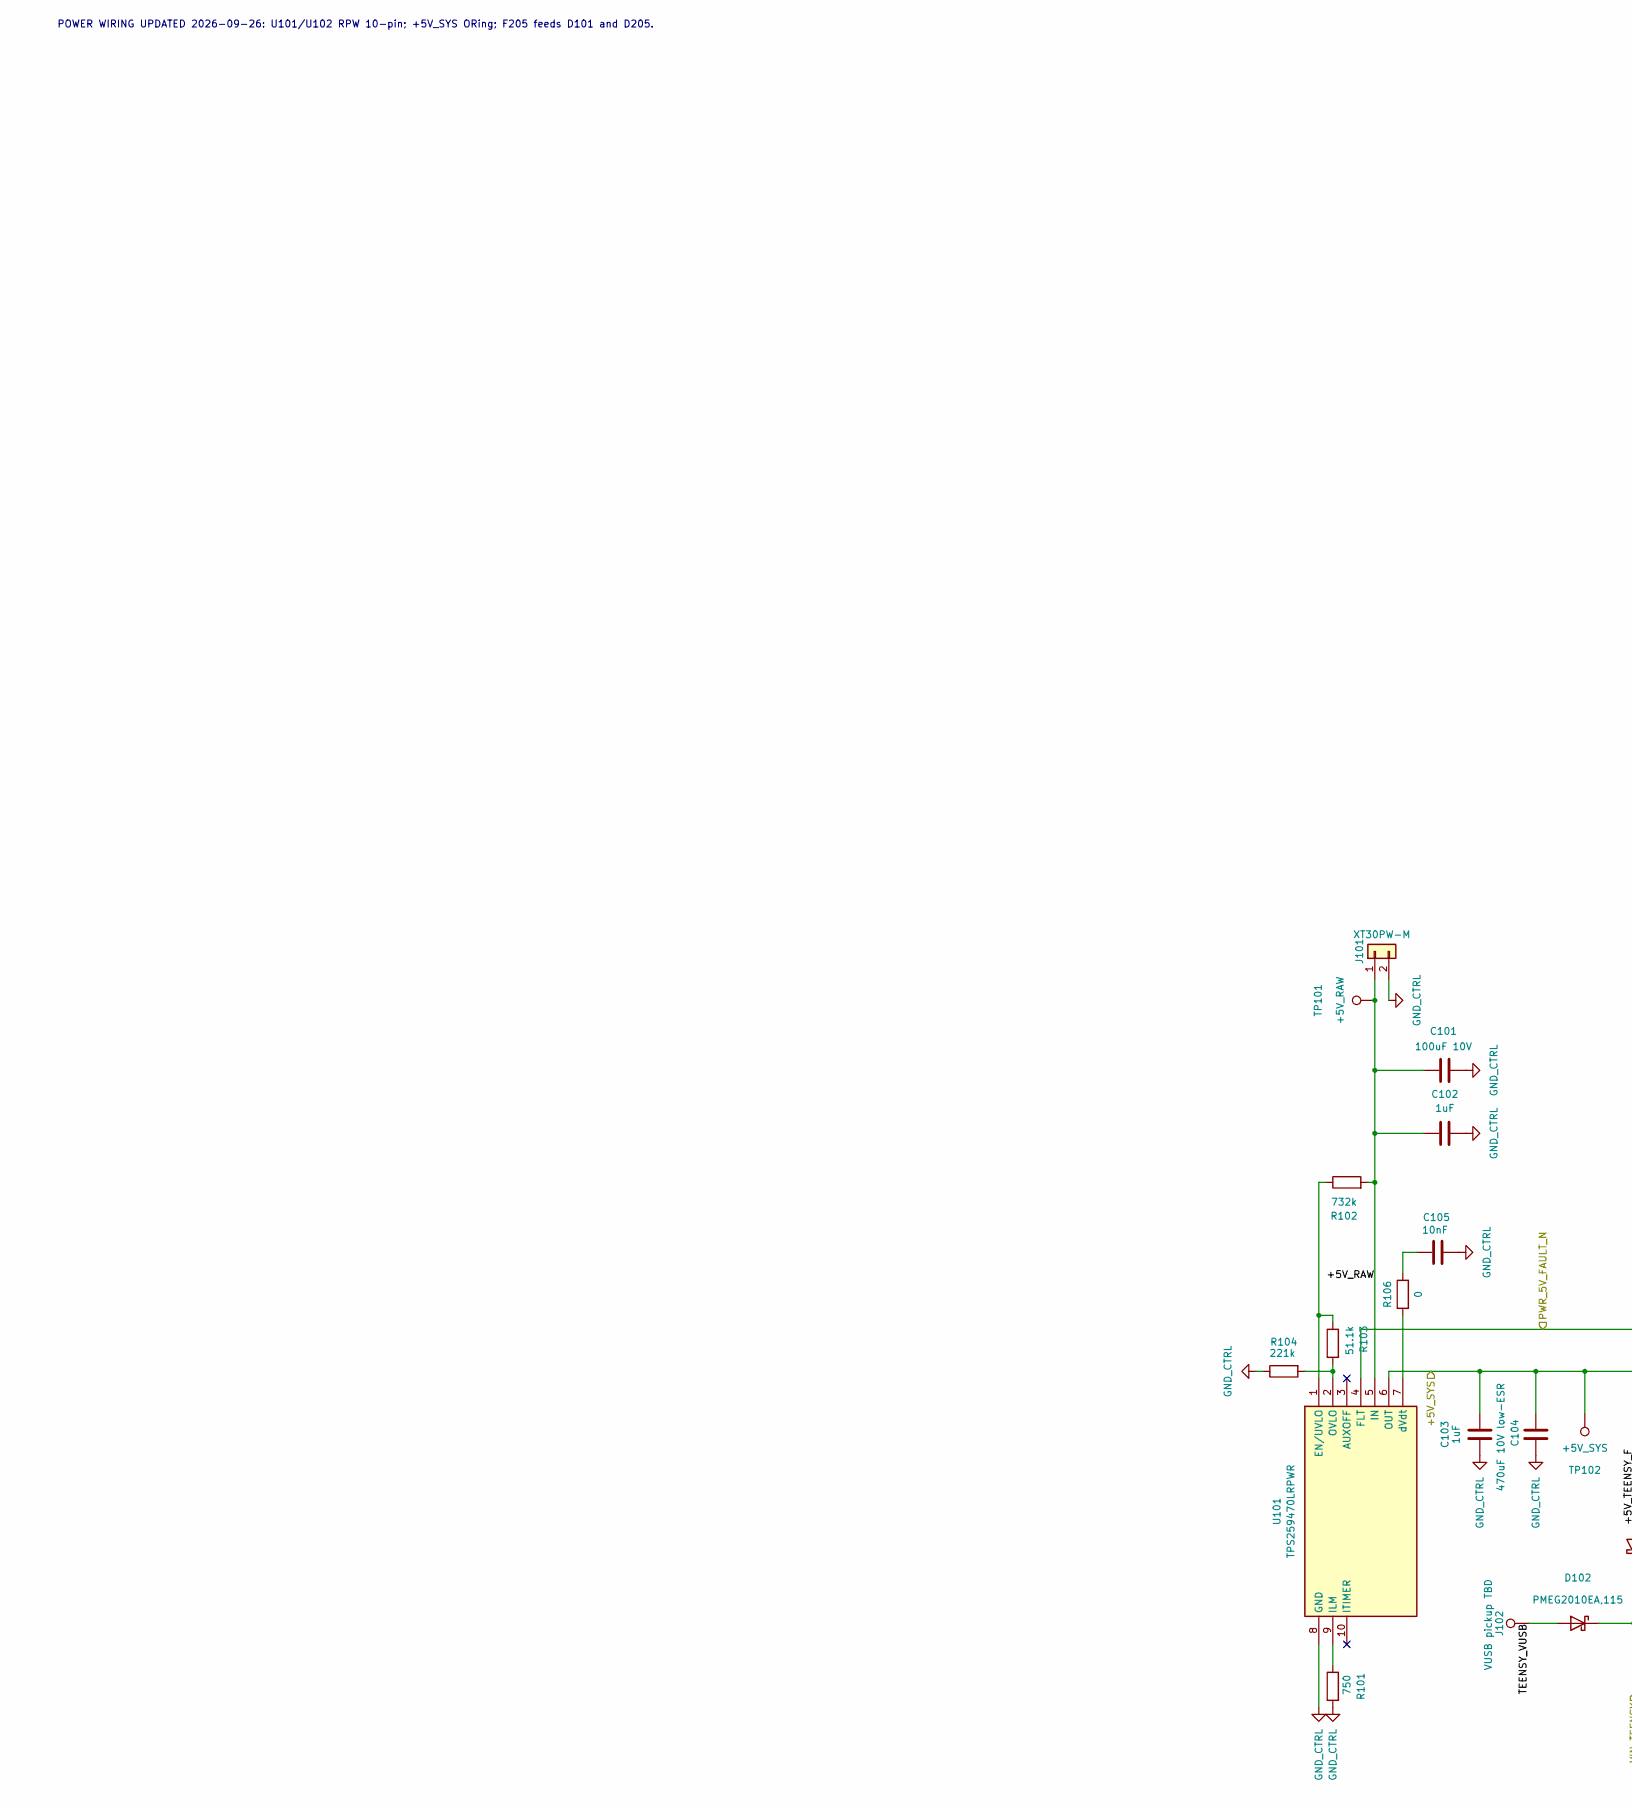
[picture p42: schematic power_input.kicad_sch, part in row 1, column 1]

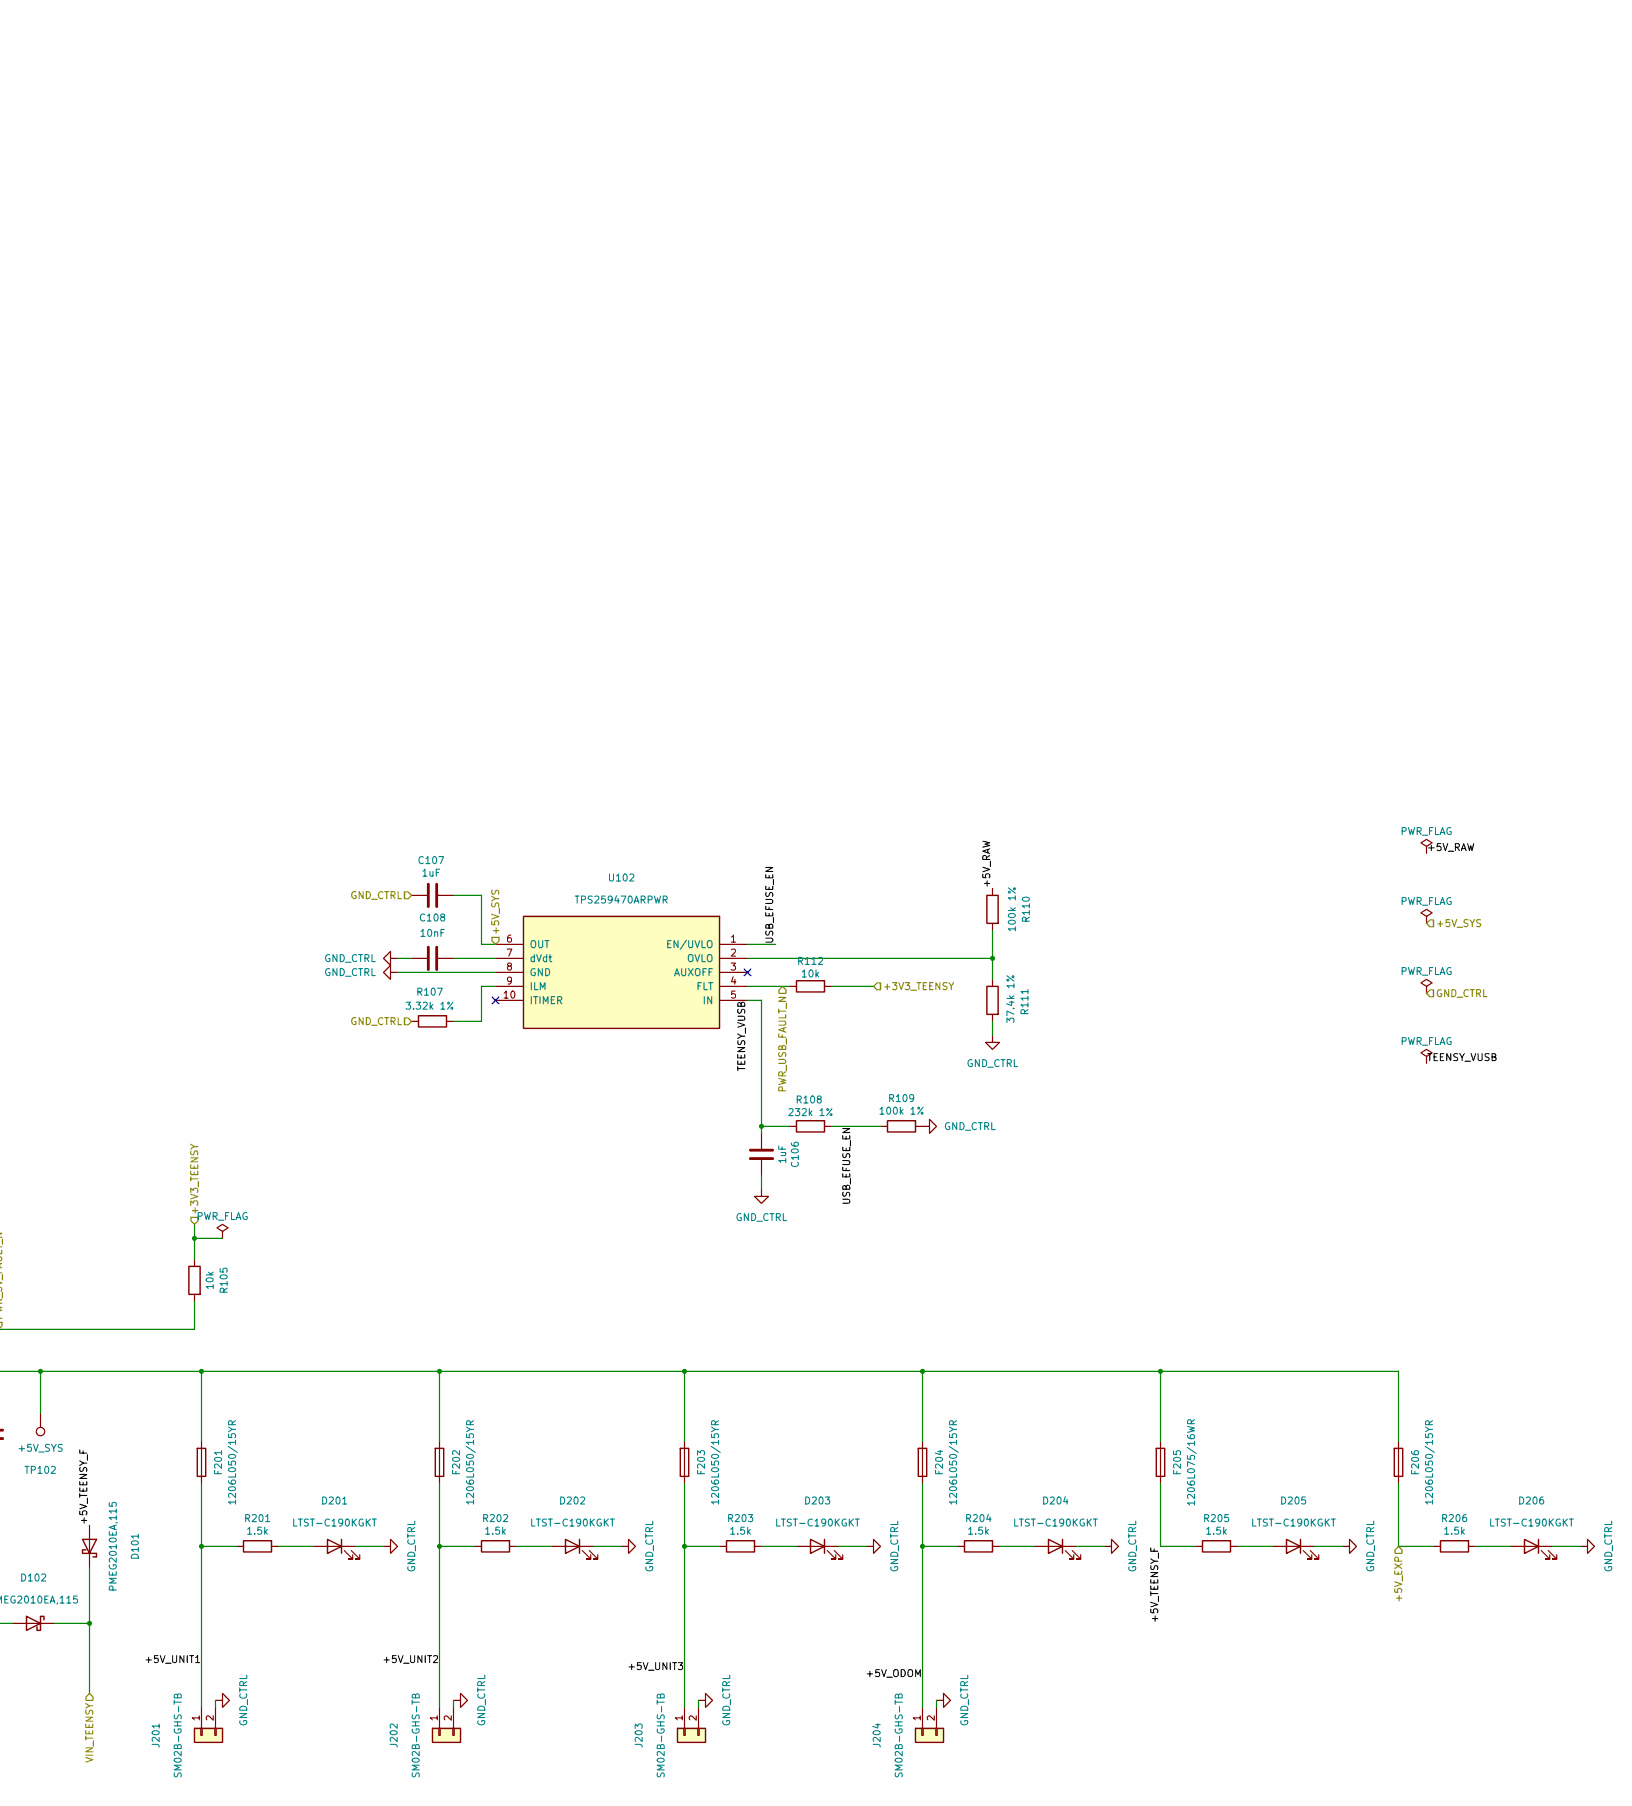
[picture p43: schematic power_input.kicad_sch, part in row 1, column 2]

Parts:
C101: 100uF 10V
C102, C103, C106, C107: 1uF; C_0603_1608Metric
C104: 470uF 10V low-ESR
C105, C108: 10nF; C_0603_1608Metric
D101, D102: PMEG2010EA,115; D_SOD-323
D201, D202, D203, D204, D205, D206: LTST-C190KGKT; LED_0603_1608Metric
F201, F202, F203, F204, F206: 1206L050/15YR; Fuse_1206_3216Metric
F205: 1206L075/16WR; Fuse_1206_3216Metric
J101: XT30PW-M; AMASS_XT30PW-M_1x02_P2.50mm_Horizontal
J102: VUSB pickup TBD
J201, J202, J203, J204: SM02B-GHS-TB; JST_GH_SM02B-GHS-TB_1x02-1MP_P1.25mm_Horizontal
R101: 750; R_0603_1608Metric
R102: 732k; R_0603_1608Metric
R103: 51.1k; R_0603_1608Metric
R104: 221k; R_0603_1608Metric
R105, R112: 10k; R_0603_1608Metric
R106: 0; R_0603_1608Metric
R107: 3.32k 1%; R_0603_1608Metric
R108: 232k 1%; R_0603_1608Metric
R109, R110: 100k 1%; R_0603_1608Metric
R111: 37.4k 1%; R_0603_1608Metric
R201, R202, R203, R204, R205, R206: 1.5k; R_0603_1608Metric
TP101: +5V_RAW; Harwin_S1751-46R
TP102: +5V_SYS; Harwin_S1751-46R
U101: TPS259470LRPWR; TPS25947_RPW_10Pin; Manufacturer_Part_Number TPS259470LRPWR; Mouser Part Number 595-TPS259470LRPWR
U102: TPS259470ARPWR; TPS25947_RPW_10Pin

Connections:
/5V input / eFuse / USB diode OR (1)/+5V_ODOM: F204.1, J204.1, R204.1
/5V input / eFuse / USB diode OR (1)/+5V_RAW: C101.1, C102.1, J101.1, R102.2, R110.1, TP101.1 (1_1), U101.5 (IN)
/5V input / eFuse / USB diode OR (1)/+5V_TEENSY_F: D101.2 (A), F205.1, R205.1
/5V input / eFuse / USB diode OR (1)/+5V_UNIT1: F201.1, J201.1, R201.1
/5V input / eFuse / USB diode OR (1)/+5V_UNIT2: F202.1, J202.1, R202.1
/5V input / eFuse / USB diode OR (1)/+5V_UNIT3: F203.1, J203.1, R203.1
/5V input / eFuse / USB diode OR (1)/TEENSY_VUSB: C106.1, D102.2 (A), J102.1, R108.1, U102.5 (IN)
/5V input / eFuse / USB diode OR (1)/USB_EFUSE_EN: R108.2, R109.1, U102.1 (EN/UVLO)
/+3V3_TEENSY: R105.1, R112.2; also elsewhere on the board
/+5V_EXP: F206.1, R206.1; also elsewhere on the board
/+5V_SYS: C103.2, C104.2, C107.2, F201.2, F202.2, F203.2, F204.2, F205.2, F206.2, TP102.1 (1_1), U101.6 (OUT), U102.6 (OUT); also elsewhere on the board
/PWR_5V_FAULT_N: R105.2, U101.4 (FLT); also elsewhere on the board
/PWR_USB_FAULT_N: R112.1, U102.4 (FLT); also elsewhere on the board
/VIN_TEENSY: D101.1 (K), D102.1 (K); also elsewhere on the board
GND_CTRL: C101.2, C102.2, C103.1, C104.1, C105.2, C106.2, C107.1, C108.1, D201.1 (K), D202.1 (K), D203.1 (K), D204.1 (K), D205.1 (K), D206.1 (K), J101.2, J201.2, J202.2, J203.2, J204.2, R101.2, R104.1, R107.1, R109.2, R111.2, U101.8 (GND), U102.8 (GND); also elsewhere on the board
unnamed: C105.1, R106.1
unnamed: D201.2 (A), R201.2
unnamed: D202.2 (A), R202.2
unnamed: D203.2 (A), R203.2
unnamed: D204.2 (A), R204.2
unnamed: D205.2 (A), R205.2
unnamed: D206.2 (A), R206.2
unnamed: R102.1, R103.1, U101.1 (EN/UVLO)
unnamed: R101.1, U101.9 (ILM)
unnamed: R103.2, R104.2, U101.2 (OVLO)
unnamed: R106.2, U101.7 (dVdt)
unnamed: R107.2, U102.9 (ILM)
unnamed: R110.2, R111.1, U102.2 (OVLO)
unnamed: C108.2, U102.7 (dVdt)

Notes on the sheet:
POWER WIRING UPDATED 2026-09-26: U101/U102 RPW 10-pin; +5V_SYS ORing; F205 feeds D101 and D205.

Board: 2 copper layers, 149 parts (0 on the bottom side), 107 nets, no tracks yet.

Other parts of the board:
H1, H2, H3, H4: MountingHole_3.2mm_M3

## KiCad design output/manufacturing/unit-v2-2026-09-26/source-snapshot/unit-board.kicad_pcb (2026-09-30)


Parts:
D6, D8: LTST-C190KGKT; LED_0603_1608Metric
D9: LTST-C190KSKT; LED_0603_1608Metric
D10: LTST-C190KRKT; LED_0603_1608Metric
J6: SM06B-GHS-TB; JST_GH_SM06B-GHS-TB_1x06-1MP_P1.25mm_Horizontal
J8: FTSH-105-01-L-DV-K-P; FTSH10501LDVKP; Manufacturer_Part_Number FTSH-105-01-L-DV-K-P; Mouser Part Number 200-FTSH10501LDVKP
J9: UART_3V3_1x03; PinHeader_1x03_P2.54mm_Vertical
R15, R16, R17, R18: 0R; R_0603_1608Metric
R19, R20, R21, R22: 1k; R_0603_1608Metric
SW3: DS04-254-1-03BK-SMT; SW_DIP_SPSTx03_Slide_Omron_A6S-310x_W8.9mm_P2.54mm

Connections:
/CAN Interface/PWR_5V: J6.6; also elsewhere on the board
/DBG_RX: J9.3; also elsewhere on the board
/DBG_TX: J9.2; also elsewhere on the board
/G474 Minimum/AMT22_CS_N: R18.2; also elsewhere on the board
/G474 Minimum/LED_COMM: R21.1; also elsewhere on the board
/G474 Minimum/LED_ERR: R22.1; also elsewhere on the board
/G474 Minimum/LED_RUN: R20.1; also elsewhere on the board
/G474 Minimum/SPI3_MISO: R17.2; also elsewhere on the board
/G474 Minimum/SPI3_MOSI: R16.2; also elsewhere on the board
/G474 Minimum/SPI3_SCK: R15.2; also elsewhere on the board
/G474 Minimum/UNIT_ID0: SW3.1; also elsewhere on the board
/G474 Minimum/UNIT_ID1: SW3.2; also elsewhere on the board
/G474 Minimum/UNIT_ID2: SW3.3; also elsewhere on the board
/NRST: J8.10; also elsewhere on the board
/SWCLK: J8.4; also elsewhere on the board
/SWDIO: J8.2; also elsewhere on the board
/SWO: J8.6; also elsewhere on the board
/VTREF_3V3: J8.1, R19.1; also elsewhere on the board
GND: D6.1 (K), D8.1 (K), D9.1 (K), D10.1 (K), J6.3, J8.3, J8.5, J8.9, J9.1, SW3.4, SW3.5, SW3.6; also elsewhere on the board
unnamed: D6.2 (A), R19.2
unnamed: D8.2 (A), R20.2
unnamed: D9.2 (A), R21.2
unnamed: D10.2 (A), R22.2
unnamed: J6.1, R18.1
unnamed: J6.2, R17.1
unnamed: J6.4, R16.1
unnamed: J6.5, R15.1

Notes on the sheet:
UART J9: 1 GND / 2 MCU TX / 3 MCU RX; 3.3V logic, no power
SWD 1.27mm 2x5; keyed header / footprint TBD
AMT-Interface
status led
CAN id
VTref = MCU 3V3 sense; pin7 KEY / pin8 TDI = NC


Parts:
C3, C4: 10pF; C_0603_1608Metric
C5, C6, C7, C8, C9, C13, C15: 100nF; C_0603_1608Metric
C10: 4.7uF; C_0805_2012Metric
C11, C14: 1uF; C_0603_1608Metric
C12: 10nF; C_0603_1608Metric
FB1: BLM18AG601SN1D; L_0603_1608Metric
R2: 0R; R_0603_1608Metric
R3: RC0603JR-070RL 0R; R_0603_1608Metric
R4: RC0603FR-0710KL 10k; R_0603_1608Metric
U4: STM32G474RET6; LQFP-64_10x10mm_P0.5mm
Y1: FC3BAEBDI8.0-T1; Crystal_SMD_3225-4Pin_3.2x2.5mm

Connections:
/CAN Interface1/CAN_RX: U4.34 (PB12); also elsewhere on the board
/CAN Interface1/CAN_TX: U4.35 (PB13); also elsewhere on the board
/CAN Interface/CAN_RX: U4.45 (PA11); also elsewhere on the board
/CAN Interface/CAN_TX: U4.46 (PA12); also elsewhere on the board
/DBG_RX: U4.17 (PA3); also elsewhere on the board
/DBG_TX: U4.14 (PA2); also elsewhere on the board
/G474 Minimum/ADC_5V_MON: U4.12 (PA0); also elsewhere on the board
/G474 Minimum/AMT22_CS_N: U4.55 (PD2); also elsewhere on the board
/G474 Minimum/BOOT0: R4.1, U4.61 (PB8)
/G474 Minimum/HSE_IN: C3.1, U4.5 (PF0), Y1.3
/G474 Minimum/HSE_OUT: R3.1, U4.6 (PF1)
/G474 Minimum/I2C_SCL: U4.51 (PA15)
/G474 Minimum/I2C_SDA: U4.60 (PB7)
/G474 Minimum/LED_COMM: U4.30 (PB10); also elsewhere on the board
/G474 Minimum/LED_ERR: U4.33 (PB11); also elsewhere on the board
/G474 Minimum/LED_RUN: U4.19 (PA5); also elsewhere on the board
/G474 Minimum/SPI3_MISO: U4.53 (PC11); also elsewhere on the board
/G474 Minimum/SPI3_MOSI: U4.54 (PC12); also elsewhere on the board
/G474 Minimum/SPI3_SCK: U4.52 (PC10); also elsewhere on the board
/G474 Minimum/UNIT_ID0: U4.38 (PC6); also elsewhere on the board
/G474 Minimum/UNIT_ID1: U4.39 (PC7); also elsewhere on the board
/G474 Minimum/UNIT_ID2: U4.40 (PC8); also elsewhere on the board
/G474 Minimum/VDDA_A: C11.1, C13.1, FB1.1, R2.1, U4.29 (VDDA)
/G474 Minimum/VREF_PLUS: C12.1, C14.1, R2.2, U4.28 (VREF+)
/NRST: C15.1, U4.7 (PG10); also elsewhere on the board
/SWCLK: U4.50 (PA14); also elsewhere on the board
/SWDIO: U4.49 (PA13); also elsewhere on the board
/SWO: U4.56 (PB3); also elsewhere on the board
/VTREF_3V3: C5.1, C6.1, C7.1, C8.1, C9.1, C10.2, FB1.2, U4.1 (VBAT), U4.16 (VDD), U4.32 (VDD), U4.48 (VDD), U4.64 (VDD); also elsewhere on the board
GND: C3.2, C4.2, C5.2, C6.2, C7.2, C8.2, C9.2, C10.1, C11.2, C12.2, C13.2, C14.2, C15.2, R4.2, U4.15 (VSS), U4.27 (VSSA), U4.31 (VSS), U4.47 (VSS), U4.63 (VSS), Y1.2 (G), Y1.4 (G); also elsewhere on the board
unnamed: C4.1, R3.2, Y1.1


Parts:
C1, C2: 100nF; C_0603_1608Metric
D1: ESD2CAN24DBZRQ1; SOT-23; Manufacturer_Part_Number ESD2CAN24DBZRQ1; Mouser Part Number 595-ESD2CAN24DBZRQ1
J2, J3: SM03B-GHS-TB; JST_GH_SM03B-GHS-TB_1x03-1MP_P1.25mm_Horizontal
R1: 120R; R_0603_1608Metric
SW1: JS102011SAQN; Manufacturer_Part_Number JS102011SAQN; Mouser Part Number 611-JS102011SAQN
U3: TCAN1051VDRQ1; SOIC-8_3.9x4.9mm_P1.27mm; Manufacturer_Part_Number TCAN1051VDRQ1; Mouser Part Number 595-TCAN1051VDRQ1

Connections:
/CAN Interface/CAN_RX: U3.4 (RXD); also elsewhere on the board
/CAN Interface/CAN_TX: U3.1 (TXD); also elsewhere on the board
/CAN Interface/COMM_A: D1.1 (IO_1), J2.1, J3.1, R1.1, U3.7 (CANH)
/CAN Interface/COMM_B: D1.2 (IO_2), J2.2, J3.2, SW1.3 (N.O.), U3.6 (CANL)
/CAN Interface/PWR_5V: C1.1, U3.3 (VCC); also elsewhere on the board
/VTREF_3V3: C2.1, U3.5 (VIO); also elsewhere on the board
GND: C1.2, C2.2, D1.3 (GND), J2.3, J3.3, U3.2 (GND), U3.8 (S); also elsewhere on the board
unnamed: R1.2, SW1.2 (COM)


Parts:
C16: GRM188R71H103KA01D 10nF; C_0603_1608Metric
D7: BAT54S-HF; SOT-23
R13: RC0603FR-0733KL 33k; R_0603_1608Metric
R14: RC0603FR-0722KL 22k; R_0603_1608Metric

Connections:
/CAN Interface/PWR_5V: R13.1; also elsewhere on the board
/G474 Minimum/ADC_5V_MON: C16.1, D7.3 (COM), R13.2, R14.1; also elsewhere on the board
/VTREF_3V3: D7.2 (K); also elsewhere on the board
GND: C16.2, D7.1 (A), R14.2; also elsewhere on the board


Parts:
C101: 2.2uF; C_0805_2012Metric
C201, C203: 100nF; C_0603_1608Metric
C202, C204: 10uF; C_0805_2012Metric
J1: SM02B-GHS-TB; JST_GH_SM02B-GHS-TB_1x02-1MP_P1.25mm_Horizontal
U1: LM66100DCKR; SOT-363_SC-70-6; Manufacturer_Part_Number LM66100DCKR; Mouser Part Number 595-LM66100DCKR
U2: TLV76133DCYR; SOT-223-3_TabPin2

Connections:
/CAN Interface/PWR_5V: C201.1, C202.1, U1.3 (~CE), U1.6 (VOUT), U2.3 (VI); also elsewhere on the board
/Power Input 3.3V/PWR_5V_IN: C101.1, J1.1, U1.1 (VIN)
/VTREF_3V3: C203.1, C204.1, U2.2 (VO); also elsewhere on the board
GND: C101.2, C201.2, C202.2, C203.2, C204.2, J1.2, U1.2 (GND), U2.1 (GND); also elsewhere on the board


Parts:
C17, C18: 100nF; C_0603_1608Metric
D2: ESD2CAN24DBZRQ1; SOT-23; Manufacturer_Part_Number ESD2CAN24DBZRQ1; Mouser Part Number 595-ESD2CAN24DBZRQ1
J4, J5: SM03B-GHS-TB; JST_GH_SM03B-GHS-TB_1x03-1MP_P1.25mm_Horizontal
U5: TCAN1051VDRQ1; SOIC-8_3.9x4.9mm_P1.27mm; Manufacturer_Part_Number TCAN1051VDRQ1; Mouser Part Number 595-TCAN1051VDRQ1

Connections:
/CAN Interface1/C620_CAN_H: D2.1 (IO_1), J4.1, J5.1, U5.7 (CANH)
/CAN Interface1/C620_CAN_L: D2.2 (IO_2), J4.2, J5.2, U5.6 (CANL)
/CAN Interface1/CAN_RX: U5.4 (RXD); also elsewhere on the board
/CAN Interface1/CAN_TX: U5.1 (TXD); also elsewhere on the board
/CAN Interface/PWR_5V: C17.1, U5.3 (VCC); also elsewhere on the board
/VTREF_3V3: C18.1, U5.5 (VIO); also elsewhere on the board
GND: C17.2, C18.2, D2.3 (GND), J4.3, J5.3, U5.2 (GND), U5.8 (S); also elsewhere on the board


Board: 4 copper layers, 45.0 x 45.0 mm, 62 parts (0 on the bottom side), 44 nets.

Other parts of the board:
QR*****: QR_GitHub_Repository

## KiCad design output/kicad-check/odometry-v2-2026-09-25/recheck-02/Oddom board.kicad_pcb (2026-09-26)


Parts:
C1: 2.2uF; C_0805_2012Metric
C2, C4, C8, C9, C11, C12, C13, C14, C22, C28: 100nF; C_0603_1608Metric
C3, C5: 10uF; C_0805_2012Metric
C6, C7: 10pF; C_0603_1608Metric
C10: 4.7uF; C_0805_2012Metric
C16: 1uF; C_0603_1608Metric
C20, C21, C27: 2.2 µF; C_0805_2012Metric
D6, D8: LTST-C190KGKT; LED_0603_1608Metric
D9: LTST-C190KSKT; LED_0603_1608Metric
D10: LTST-C190KRKT; LED_0603_1608Metric
FB1: BLM18AG601SN1D; L_0603_1608Metric
J1: SM02B-GHS-TB; JST_GH_SM02B-GHS-TB_1x02-1MP_P1.25mm_Horizontal
J3: FTSH-105-01-L-DV-K-P; FTSH10501LDVKP; Manufacturer_Part_Number FTSH-105-01-L-DV-K-P; Mouser Part Number 200-FTSH10501LDVKP
J7: Conn_01x08; JST_XH_B8B-XH-AM_1x08_P2.50mm_Vertical
J9: UART_3V3_1x03; PinHeader_1x03_P2.54mm_Vertical
R3: RC0603JR-070RL 0R; R_0603_1608Metric
R4: RC0603FR-0710KL 10k; R_0603_1608Metric
R19, R20, R21, R22: 1k; R_0603_1608Metric
SW3: DS04-254-1-03BK-SMT; SW_DIP_SPSTx03_Slide_Omron_A6S-310x_W8.9mm_P2.54mm
U1: STM32F405RGTx; LQFP-64_10x10mm_P0.5mm
U2: TLV76133DCYR; SOT-223-3_TabPin2
U5: LM66100DCKR; SOT-363_SC-70-6; Manufacturer_Part_Number LM66100DCKR; Mouser Part Number 595-LM66100DCKR
Y1: FC3BAEBDI8.0-T1; Crystal_SMD_3225-4Pin_3.2x2.5mm

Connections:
/AMT102_input1/W1_A: U1.22 (PA6); also elsewhere on the board
/AMT102_input1/W1_B: U1.23 (PA7); also elsewhere on the board
/AMT102_input2/W1_A: U1.58 (PB6); also elsewhere on the board
/AMT102_input2/W1_B: U1.59 (PB7); also elsewhere on the board
/AMT102_input/W1_A: U1.14 (PA0); also elsewhere on the board
/AMT102_input/W1_B: U1.15 (PA1); also elsewhere on the board
/BOOT0: R4.2, U1.60 (BOOT0)
/CAN_interface/COMM_RX: U1.44 (PA11); also elsewhere on the board
/CAN_interface/COMM_TX: U1.45 (PA12); also elsewhere on the board
COMM: R21.1, U1.29 (PB10)
ERR: R22.1, U1.30 (PB11)
GND: C1.2, C2.2, C3.2, C4.2, C5.2, C6.2, C7.2, C8.2, C9.2, C10.1, C11.2, C12.2, C13.2, C14.2, C16.2, C20.2, C21.2, C22.2, C27.2, C28.1, D6.1 (K), D8.1 (K), D9.1 (K), D10.1 (K), J1.2, J3.3, J3.5, J3.9, J7.2, J9.1, R4.1, SW3.4, SW3.5, SW3.6, U1.12 (VSSA), U1.18 (VSS), U1.63 (VSS), U2.1 (GND), U5.2 (GND), Y1.2 (G), Y1.4 (G); also elsewhere on the board
IMU_CS_N: J7.6, U1.54 (PD2)
IMU_INT1: J7.7, U1.24 (PC4)
IMU_INT2: J7.8, U1.25 (PC5)
NRST: C22.1, J3.10, U1.7 (NRST)
unnamed: C6.1, R3.2, Y1.1
unnamed: D6.2 (A), R19.2
unnamed: D8.2 (A), R20.2
unnamed: D9.2 (A), R21.2
unnamed: D10.2 (A), R22.2
unnamed: C1.1, J1.1, U5.1 (VIN)
unnamed: J7.3, U1.52 (PC11)
unnamed: J7.4, U1.53 (PC12)
unnamed: J7.5, U1.51 (PC10)
unnamed: SW3.1, U1.37 (PC6)
unnamed: SW3.2, U1.38 (PC7)
unnamed: SW3.3, U1.39 (PC8)
unnamed: C7.1, U1.5 (PH0), Y1.3
unnamed: R3.1, U1.6 (PH1)
unnamed: C20.1, U1.31 (VCAP_1)
unnamed: C21.1, U1.47 (VCAP_2)
unnamed: C14.1, C16.1, FB1.1, U1.13 (VDDA)
PWR_3.3V: C4.1, C5.1, C8.1, C9.1, C10.2, C11.1, C12.1, C13.1, C27.1, C28.2, FB1.2, J3.1, J7.1, R19.1, U1.1 (VBAT), U1.19 (VDD), U1.32 (VDD), U1.48 (VDD), U1.64 (VDD), U2.2 (VO); also elsewhere on the board
PWR_5V: C2.1, C3.1, U2.3 (VI), U5.3 (~CE), U5.6 (VOUT); also elsewhere on the board
RUN: R20.1, U1.21 (PA5)
SWCLK: J3.4, U1.49 (PA14)
SWDIO: J3.2, U1.46 (PA13)
SWO: J3.6, U1.55 (PB3)
USART2_RX: J9.3, U1.17 (PA3)
USART2_TX: J9.2, U1.16 (PA2)

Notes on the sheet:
UART J9: 1 GND / 2 MCU TX / 3 MCU RX; 3.3V logic, no power
SWD 1.27mm 2x5; keyed header / footprint TBD
VTref = MCU digital 3V3 sense; pin7 KEY / pin8 TDI = NC


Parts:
D2: D_TVS_Dual_AACESDS452DBZ; SOT-23
J4: Conn_01x04; JST_XH_B4B-XH-AM_1x04_P2.50mm_Vertical
R2, R5: 100R; R_0603_1608Metric
U3: 74LVC2G17; SOT-23-6

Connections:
/AMT102_input/W1_A: U3.6; also elsewhere on the board
/AMT102_input/W1_B: U3.4; also elsewhere on the board
GND: D2.3 (common), J4.4, U3.2 (GND); also elsewhere on the board
unnamed: D2.1 (A1), J4.3, R5.1
unnamed: D2.2 (A2), J4.1, R2.1
unnamed: R2.2, U3.1
unnamed: R5.2, U3.3
PWR_3.3V: U3.5 (VCC); also elsewhere on the board
PWR_5V: J4.2; also elsewhere on the board

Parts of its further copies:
D3, D4: D_TVS_Dual_AACESDS452DBZ; SOT-23
J5, J6: Conn_01x04; JST_XH_B4B-XH-AM_1x04_P2.50mm_Vertical
R6, R7, R8, R9: 100R; R_0603_1608Metric
U7, U9: 74LVC2G17; SOT-23-6

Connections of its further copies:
/AMT102_input1/W1_A: U7.6; also elsewhere on the board
/AMT102_input1/W1_B: U7.4; also elsewhere on the board
/AMT102_input2/W1_A: U9.6; also elsewhere on the board
/AMT102_input2/W1_B: U9.4; also elsewhere on the board
GND: D3.3 (common), D4.3 (common), J5.4, J6.4, U7.2 (GND), U9.2 (GND); also elsewhere on the board
unnamed: D3.1 (A1), J5.3, R7.1
unnamed: D3.2 (A2), J5.1, R6.1
unnamed: D4.1 (A1), J6.3, R9.1
unnamed: D4.2 (A2), J6.1, R8.1
unnamed: R6.2, U7.1
unnamed: R7.2, U7.3
unnamed: R8.2, U9.1
unnamed: R9.2, U9.3
PWR_3.3V: U7.5 (VCC), U9.5 (VCC); also elsewhere on the board
PWR_5V: J5.2, J6.2; also elsewhere on the board


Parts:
C18, C19: 100nF; C_0603_1608Metric
D1: ESD2CAN24DBZRQ1; SOT-23; Manufacturer_Part_Number ESD2CAN24DBZRQ1; Mouser Part Number 595-ESD2CAN24DBZRQ1
J8: BM03B-GHS-TBT_LF__SN_; BM03BGHSTBTLFSN; Manufacturer_Part_Number BM03B-GHS-TBT(LF)(SN); Mouser Part Number 306-BM03BGHSTBTLFSNN
R1: 120R; R_0603_1608Metric
SW1: JS102011SAQN; Manufacturer_Part_Number JS102011SAQN; Mouser Part Number 611-JS102011SAQN
U4: TCAN1051VDRQ1; SOIC-8_3.9x4.9mm_P1.27mm; Manufacturer_Part_Number TCAN1051VDRQ1; Mouser Part Number 595-TCAN1051VDRQ1

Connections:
/CAN_interface/COMM_RX: U4.4 (RXD); also elsewhere on the board
/CAN_interface/COMM_TX: U4.1 (TXD); also elsewhere on the board
GND: C18.2, C19.2, D1.3 (GND), J8.3, U4.2 (GND), U4.8 (S); also elsewhere on the board
unnamed: D1.1 (IO_1), J8.1, R1.1, U4.7 (CANH)
unnamed: D1.2 (IO_2), J8.2, SW1.3 (N.O.), U4.6 (CANL)
unnamed: R1.2, SW1.2 (COM)
PWR_3.3V: C19.1, U4.5 (VIO); also elsewhere on the board
PWR_5V: C18.1, U4.3 (VCC); also elsewhere on the board


Board: 4 copper layers, 65.0 x 30.0 mm, 62 parts (0 on the bottom side), 56 nets.

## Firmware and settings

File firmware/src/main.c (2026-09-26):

/* CAN target bench app. The unit boots disabled, accepts SET_TARGET on the
 * central CAN bus, and only drives after UNIT_CTRL enable.
 * Wheel must be lifted clear of the ground (free-spinning) before enabling.
 *
 * No rpm-tracking divergence guard: current_limit already hard-clamps every
 * motor command, so a wheel-rpm-error threshold only added false trips on the
 * expected breakaway kick (see 2026-07-06 notes in CONTROL_LOOP_TUNING.md —
 * open-loop test confirmed breakaway happens cleanly around 850raw, current
 * feedback has no glitches). Stops are just B1 press, sensor/C620 feedback
 * timeout, steer angle divergence, or the fixed test duration.
 * Kinetic-friction feedforward and drive-integral floor exist in the
 * controller but default to 0 (disabled) here; SET_CONFIG (0x140+unitId) can
 * tune them live to address the low-rpm stick-slip limit cycle without a
 * reflash. */

#include <stdbool.h>
#include <stdint.h>

#include "config/steer_calibration.h"
#include "control/unit_controller.h"
#include "platform/amt22.h"
#include "platform/bench_uart.h"
#include "platform/calibration_flash.h"
#include "platform/clock.h"
#include "platform/fdcan.h"
#include "platform/gpio.h"
#include "platform/uart.h"
#include "protocol/c620.h"

/* Bench-only transport: ESP32 GPIO UART -> USART1 PA9/PA10. Production
 * architecture remains the central CAN-FD bus. */
#define BENCH_CONTROL_UART_ENABLED 1
#define BENCH_SAVE_CURRENT_ZERO_ON_BOOT 0

enum {
    CONTROL_PERIOD_MS = 1U,
    FEEDBACK_TIMEOUT_MS = 20U,
    REPORT_PERIOD_MS = 100U,
    /* Disabled-state angle report so a UI can seed its steer target from the
     * actual angle before the first enable (run= lines only print while
     * active). */
    IDLE_REPORT_PERIOD_MS = 500U,
    ANGLE_DIVERGENCE_STOP_DEG_MILLI = 120000U,
    MOTOR_TEMPERATURE_LIMIT_C = 80U,
    M3508_INTERNAL_REDUCTION = 19U,
    UNIT_ID = 1U,
    CAN_ID_SET_TARGET_BASE = 0x100U,
    CAN_ID_SET_TARGET = CAN_ID_SET_TARGET_BASE + UNIT_ID,
    CAN_ID_SET_TARGET_FF_BASE = 0x110U,
    CAN_ID_SET_TARGET_FF = CAN_ID_SET_TARGET_FF_BASE + UNIT_ID,
    CAN_ID_UNIT_CTRL_BASE = 0x120U,
    CAN_ID_UNIT_CTRL = CAN_ID_UNIT_CTRL_BASE + UNIT_ID,
    UNIT_CTRL_SET_ENABLE = 0x01U,
    UNIT_CTRL_CALIB_START = 0x02U,
    UNIT_CTRL_CALIB_SAVE_ZERO = 0x03U,
    UNIT_CTRL_CALIB_CLEAR = 0x04U,
    UNIT_CTRL_PING = 0x05U,
    CAN_ID_SET_CONFIG_BASE = 0x140U,
    CAN_ID_SET_CONFIG = CAN_ID_SET_CONFIG_BASE + UNIT_ID,
    /* Classic-CAN bench companion to TRAJECTORY_FD.thetaDDot.  Production
     * coordinated control will carry this value in TRAJECTORY_FD; keeping a
     * separate 8-byte frame here lets the current MTU=16 bench exercise the
     * same explicit-acceleration path without changing SET_TARGET_FF. */
    CAN_ID_SET_TARGET_ACCEL_FF_BASE = 0x160U,
    CAN_ID_SET_TARGET_ACCEL_FF = CAN_ID_SET_TARGET_ACCEL_FF_BASE + UNIT_ID,
    CAN_ID_STATUS1_BASE = 0x180U,
    CAN_ID_STATUS1 = CAN_ID_STATUS1_BASE + UNIT_ID,
    CAN_ID_STATUS2_BASE = 0x190U,
    CAN_ID_STATUS2 = CAN_ID_STATUS2_BASE + UNIT_ID,
    CAN_ID_STATUS3_BASE = 0x1A0U,
    CAN_ID_STATUS3 = CAN_ID_STATUS3_BASE + UNIT_ID,
    CAN_ID_UNIT_STATUS_DIAG_BASE = 0x1B0U,
    CAN_ID_UNIT_STATUS_DIAG = CAN_ID_UNIT_STATUS_DIAG_BASE + UNIT_ID,
    CAN_ID_CALIB_RESULT_BASE = 0x1C0U,
    CAN_ID_CALIB_RESULT = CAN_ID_CALIB_RESULT_BASE + UNIT_ID,
    TARGET_TIMEOUT_MS = 200U,
    STATUS1_NORMAL_PERIOD_MS = 20U,
    STATUS2_NORMAL_PERIOD_MS = 50U,
    STATUS3_PERIOD_MS = 20U,
    SETTLE_DWELL_MS = 100U,
    /* docs/communication/COMMUNICATION_NAMING_AND_IDS.md "SET_TARGET_FF
     * payload": sender is assumed to publish at >=50Hz; 200ms is the
     * documented staleness bound before the FF must fall back to 0. */
    TARGET_FF_TIMEOUT_MS = 200U,
    /* mdeg/s -> rpm: /1000 (mdeg->deg) then /6 (deg/s->rpm) = /6000. */
    STEER_RATE_FF_MDEG_PER_S_TO_RPM_DIV = 6000,
    /* mdeg/s^2 -> axis rpm/s uses the same degree/revolution conversion. */
    STEER_ACCEL_FF_MDEG_PER_S2_TO_RPM_PER_S_DIV = 6000,
};

enum {
    STATUS_FLAG_ACTIVE = 1U << 0,
    STATUS_FLAG_TARGET_FRESH = 1U << 1,
    STATUS_FLAG_FEEDBACK_OK = 1U << 2,
    STATUS_FLAG_AMT_OK = 1U << 3,
    STATUS_FLAG_STEER_IN_BAND = 1U << 4,
    STATUS_FLAG_WHEEL_IN_BAND = 1U << 5,
    STATUS_FLAG_MOTION_SETTLED = 1U << 6,
    STATUS_FLAG_LIMITING_ACTIVE = 1U << 7,
    STATUS_FLAG_CALIBRATED = 1U << 8,
    STATUS_FLAG_CONFIG_CRC_ERROR = 1U << 9,
    STATUS_FLAG_CALIB_PAGE_FULL = 1U << 10,
    STATUS_FLAG_TORQUE_SCALING_ACTIVE = 1U << 11,
    STATUS_FLAG_STEER_BRAKING_ACTIVE = 1U << 12,
};

enum {
    ERROR_FLAG_NOT_CALIBRATED = 1UL << 6,
    ERROR_FLAG_CONFIG_CRC = 1UL << 8,
};

enum {
    CALIB_RESULT_CALIBRATED = 1U << 0,
    CALIB_RESULT_CRC_ERROR = 1U << 1,
    CALIB_RESULT_PAGE_FULL = 1U << 2,
    CALIB_RESULT_LAST_OP_FAILED = 1U << 3,
    CALIB_RESULT_RAW_FRESH = 1U << 4,
};

#define SETTLE_ANGLE_BAND_DEG 0.5f
#define SETTLE_STEER_AXIS_RPM 1.0f
#define SETTLE_WHEEL_MIN_BAND_RPM 12.0f
#define SETTLE_WHEEL_RELATIVE_BAND 0.06f
#define SETTLE_WHEEL_ACCEL_MILLI_RPM_PER_S 1000
#define SETTLE_FF_AXIS_RPM 0.1f
#define DRIVE_RATIO (32.0f / 11.0f)
#define STEER_RATIO (8.0f / 11.0f)

typedef struct {
    c620_feedback_t feedback;
    uint32_t last_rx_ms;
    bool received;
} motor_state_t;

static motor_state_t motors[2];
static unit_controller_t controller;
static unit_control_output_t output;
static bool unit_enabled = false;
/* A local safety stop must not be undone by the next 20ms UART frame while
 * the operator still holds the deadman. It is cleared only after an explicit
 * enable=0 frame (R1 released). */
static bool enable_rearm_required = false;
static bool target_received = false;
static uint32_t last_target_ms = 0U;
static uint32_t last_target_log_ms = 0U;
static float can_target_wheel_rpm = 0.0f;
static float can_target_steer_deg = 0.0f;
/* SET_TARGET_FF (0x110+unitId): steer angular-rate FF applied to the
 * controller, plus wheel-accel FF received/logged only (not yet consumed by
 * the controller -- reserved for a future extension). */
static bool ff_received = false;
static uint32_t last_ff_ms = 0U;
static uint32_t last_ff_log_ms = 0U;
static float can_steer_rate_ff_rpm = 0.0f;
/* Legacy fallback derived from SET_TARGET_FF receive intervals. */
static float can_steer_accel_ff_rpm_per_s = 0.0f;
static int32_t can_wheel_accel_ff_rpm_milli_per_s = 0;
/* Explicit bench thetaDDot. Fresh explicit data takes precedence over the
 * receive-time derivative above; timeout restores backward compatibility. */
static bool accel_ff_received = false;
static uint32_t last_accel_ff_ms = 0U;
static float can_explicit_steer_accel_ff_rpm_per_s = 0.0f;
static float applied_steer_rate_ff_rpm = 0.0f;
static float applied_steer_accel_ff_rpm_per_s = 0.0f;
static bool applied_steer_accel_ff_is_explicit = false;
/* Normal STATUS periods are defined above. SET_CONFIG index 22 temporarily
 * overrides STATUS1/2 to 1..100ms for bench identification; zero restores
 * the normal 20/50ms periods. */
static uint32_t status_period_ms = 0U;
static bool steer_in_band = false;
static bool wheel_in_band = false;
static bool motion_settled = false;
static bool settle_candidate_active = false;
static uint32_t settle_candidate_since_ms = 0U;
static bool latest_amt_ok = false;
static uint16_t latest_amt_position = 0U;
static uint32_t latest_amt_ms = 0U;
static bool calibration_last_op_failed = false;

static int32_t to_milli(float value)
{
    const float scaled = value * 1000.0f;
    return (int32_t)(scaled >= 0.0f ? scaled + 0.5f : scaled - 0.5f);
}

static float absf(float value)
{
    return value < 0.0f ? -value : value;
}

static float clampf(float value, float minimum, float maximum)
{
    if (value < minimum) {
        return minimum;
    }
    if (value > maximum) {
        return maximum;
    }
    return value;
}

static int32_t read_i32_le(const uint8_t *data)
{
    const uint32_t raw =
        (uint32_t)data[0] |
        ((uint32_t)data[1] << 8U) |
        ((uint32_t)data[2] << 16U) |
        ((uint32_t)data[3] << 24U);
    return (int32_t)raw;
}

static void write_i32_le(uint8_t *data, int32_t value)
{
    const uint32_t raw = (uint32_t)value;
    data[0] = (uint8_t)raw;
    data[1] = (uint8_t)(raw >> 8U);
    data[2] = (uint8_t)(raw >> 16U);
    data[3] = (uint8_t)(raw >> 24U);
}

static void write_u16_le(uint8_t *data, uint16_t value)
{
    data[0] = (uint8_t)value;
    data[1] = (uint8_t)(value >> 8U);
}

static void write_i16_le(uint8_t *data, int16_t value)
{
    write_u16_le(data, (uint16_t)value);
}

static int16_t float_to_i16(float value)
{
    const float clamped = clampf(value, -32768.0f, 32767.0f);
    return (int16_t)(clamped >= 0.0f ? clamped + 0.5f : clamped - 0.5f);
}

static uint16_t float_to_u16_scaled(float value, float scale)
{
    const float scaled = clampf(value * scale, 0.0f, 65535.0f);
    return (uint16_t)(scaled + 0.5f);
}

static void write_u32_le(uint8_t *data, uint32_t value)
{
    data[0] = (uint8_t)value;
    data[1] = (uint8_t)(value >> 8U);
    data[2] = (uint8_t)(value >> 16U);
    data[3] = (uint8_t)(value >> 24U);
}

static void reset_settle_state(void)
{
    steer_in_band = false;
    wheel_in_band = false;
    motion_settled = false;
    settle_candidate_active = false;
    settle_candidate_since_ms = 0U;
}

static bool target_is_fresh(uint32_t now_ms)
{
    return target_received &&
           (uint32_t)(now_ms - last_target_ms) < TARGET_TIMEOUT_MS;
}

static bool ff_is_fresh(uint32_t now_ms)
{
    return ff_received &&
           (uint32_t)(now_ms - last_ff_ms) < TARGET_FF_TIMEOUT_MS;
}

static bool explicit_accel_ff_is_fresh(uint32_t now_ms)
{
    return accel_ff_received &&
           (uint32_t)(now_ms - last_accel_ff_ms) < TARGET_FF_TIMEOUT_MS;
}

static bool calibration_raw_is_fresh(uint32_t now_ms)
{
    return latest_amt_ok && (uint32_t)(now_ms - latest_amt_ms) < 100U;
}

static bool calibration_motion_is_stopped(uint32_t now_ms)
{
    return !unit_enabled && calibration_raw_is_fresh(now_ms) &&
           motors[0].received && motors[1].received &&
           (uint32_t)(now_ms - motors[0].last_rx_ms) < FEEDBACK_TIMEOUT_MS &&
           (uint32_t)(now_ms - motors[1].last_rx_ms) < FEEDBACK_TIMEOUT_MS &&
           motors[0].feedback.rpm >= -(int16_t)M3508_INTERNAL_REDUCTION &&
           motors[0].feedback.rpm <= (int16_t)M3508_INTERNAL_REDUCTION &&
           motors[1].feedback.rpm >= -(int16_t)M3508_INTERNAL_REDUCTION &&
           motors[1].feedback.rpm <= (int16_t)M3508_INTERNAL_REDUCTION;
}

static void send_calibration_result(uint32_t now_ms)
{
    const calibration_flash_status_t calibration = calibration_flash_status();
    uint16_t flags = 0U;
    flags |= calibration.calibrated ? CALIB_RESULT_CALIBRATED : 0U;
    flags |= calibration.crc_error ? CALIB_RESULT_CRC_ERROR : 0U;
    flags |= calibration.page_full ? CALIB_RESULT_PAGE_FULL : 0U;
    flags |= calibration_last_op_failed ? CALIB_RESULT_LAST_OP_FAILED : 0U;
    flags |= calibration_raw_is_fresh(now_ms) ? CALIB_RESULT_RAW_FRESH : 0U;
    fdcan_frame_t frame = {
        .id = CAN_ID_CALIB_RESULT,
        .dlc = 8U,
        .extended = false,
        .remote = false,
    };
    write_u16_le(&frame.data[0], calibration.calibrated
        ? calibration.zero_position_counts : UINT16_MAX);
    write_u16_le(&frame.data[2], calibration_raw_is_fresh(now_ms)
        ? latest_amt_position : UINT16_MAX);
    write_u16_le(&frame.data[4], (uint16_t)calibration.sequence);
    write_u16_le(&frame.data[6], flags);
    (void)fdcan_send(FDCAN_BUS_CENTRAL, &frame);
}

static void handle_calibration_command(uint8_t command, uint32_t now_ms)
{
    bool attempted = false;
    bool ok = true;
    if (command == UNIT_CTRL_CALIB_START || command == UNIT_CTRL_PING) {
        ok = command == UNIT_CTRL_PING || !unit_enabled;
    } else if (command == UNIT_CTRL_CALIB_SAVE_ZERO) {
        attempted = true;
        ok = calibration_motion_is_stopped(now_ms) &&
             calibration_flash_save_zero(latest_amt_position);
    } else if (command == UNIT_CTRL_CALIB_CLEAR) {
        attempted = true;
        ok = calibration_motion_is_stopped(now_ms) &&
             calibration_flash_clear();
    } else {
        return;
    }
    calibration_last_op_failed = !ok;
    const calibration_flash_status_t calibration = calibration_flash_status();
    debug_printf("CALIB cmd=%u ok=%u raw=%u zero=%u seq=%u flags=%x\n",
                 (uint32_t)command, ok ? 1U : 0U,
                 calibration_raw_is_fresh(now_ms)
                     ? (uint32_t)latest_amt_position : UINT32_MAX,
                 calibration.calibrated
                     ? (uint32_t)calibration.zero_position_counts : UINT32_MAX,
                 calibration.sequence,
                 (calibration.calibrated ? CALIB_RESULT_CALIBRATED : 0U) |
                 (calibration.crc_error ? CALIB_RESULT_CRC_ERROR : 0U) |
                 (calibration.page_full ? CALIB_RESULT_PAGE_FULL : 0U) |
                 (!ok ? CALIB_RESULT_LAST_OP_FAILED : 0U));
    if (attempted && ok) {
        unit_controller_reset(&controller);
        reset_settle_state();
    }
    send_calibration_result(now_ms);
}
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
int main(void)
{
    static const unit_controller_config_t control_config = {
        .motor_max_rpm = 469.0f,
        /* Rescaled x4 on 2026-07-08 when STEER_RATIO was corrected 2/11->8/11
         * (values are true steer-axis rpm now); physical behavior identical
         * to the tuned 10rpm/150 set: 90deg step <0.5deg in ~0.7-0.9s. */
        /* 40->60rpm commissioning stage accepted 26/26 across wheel=0/265,
         * absolute-angle boundary and 90deg tests on 2026-07-31. */
        .steer_max_rpm = 60.0f,
        .steer_min_rpm = 0.0f,
        .steer_accel_rpm_per_s = 600.0f,
        /* 4000 + drive Kp=30 + current_limit 4000: 0->500rpm rise 0.41s,
         * full +-500 reversal 0.51s, steer held <1.2deg, current peak
         * ~3700, temp 29C (2026-07-08, user-approved limit raise). */
        .wheel_accel_rpm_per_s = 4000.0f,
        .angle_kp_rpm_per_deg = 4.0f,
        .moving_angle_kp_rpm_per_deg = 1.0f,
        .angle_deadband_deg = 0.3f,
        /* High-rate STATUS-based repeat test selected 120/50 with a 2ms
         * measured-mode filter. 11/12 moves met the 0.5deg dwell criterion;
         * the remaining cold/static-friction case ended at 0.088deg but
         * entered the band too late. This is the best current gain-only
         * package; see auto-tune/2026-07-30T17-31-36Z.
         *
         * 2026-07-31: a wheel=0 outer-loop-disabled step/PRBS grid found
         * Kp=60/Ki=100 gives a cleaner isolated mode-velocity step response
         * (0% overshoot vs 34% for Kp=120 at Ki=0). Tried it as the new
         * default and flashed it, but a same-day closed-loop A/B via
         * unit_web_ui.py's production profile + MOTION_SETTLED (the metric
         * that actually matters) showed it REGRESSES real 90deg convergence:
         * ~1.8-3.7s (one 6s+ non-convergence) vs 120/50's steady ~1.1-1.2s
         * over 6 trials each. Lower Kp slows the inner loop's response to
         * the outer angle-P loop's velocity commands enough to hurt final
         * approach/settling, which the open-loop mode-step test can't see.
         * Reverted to 120/50. Lesson: validate any inner-loop candidate
         * against the full closed-loop MOTION_SETTLED metric before
         * adopting it, not just the isolated step/PRBS response. */
        .steer_mode_kp = 120.0f,
        .steer_mode_ki = 50.0f,
        .steer_brake_kp_multiplier = 1.0f,
        /* Kp=20 also trims the integral-floor overspeed bias at 25rpm to
         * ~+8% with no stick (see CONTROL_LOOP_TUNING.md 2026-07-08). */
        .drive_mode_kp = 30.0f,
        .drive_mode_ki = 20.0f,
        /* Enabled only after saturation A/B. Zero exactly preserves the
         * adopted conditional-integration controller. */
        .steer_mode_backcalc_gain = 0.0f,
        .drive_mode_backcalc_gain = 0.0f,
        /* Above worst-case breakaway (~850-950 raw, 2026-07-05/06 measurements) so the
         * integral can still defeat static friction, below current_limit so a
         * stuck-phase charge cannot release as a full-limit jump. */
        .mode_integral_limit = 1200.0f,
        .mode_rpm_filter_tau_s = 0.002f,
        .steer_schedule_filter_tau_s = 0.010f,
        /* Complementary observer: motor-mode velocity is the high-frequency
         * predictor, AMT22 angle corrects drift over 50ms. The estimated rate
         * schedules friction FF; angle feedback and settled checks stay raw. */
        .steer_observer_correction_tau_s = 0.050f,
        /* Raised 2000->4000 (~4.9A, M3508 rated 10A continuous) with user
         * approval 2026-07-08; acceleration peaks reach ~3700 with temps
         * steady at 29C on the bench. SET_CONFIG ceiling is 6000. */
        .current_limit = 4000.0f,
        .steer_motor_sign = 1.0f,
        /* Measured inertial FF gain at the adopted high-acceleration profile;
         * reduces braking overshoot without reaching the current clamp. */
        .steer_accel_ff_current_per_mode_rpm_per_s = 0.5f,
        .steer_decel_ff_current_per_mode_rpm_per_s = 0.5f,
        /* 2026-07-31: tapered to 0 above WHEEL_LOW_SPEED_TRANSITION_RPM=30 in
         * unit_controller.c, so this only assists the wheel=0/near-0 case
         * (the stick-slip stall diagnosis and A/B in firmware/PROGRESS.md).
         * A flat (non-tapered) 200-300 fixed the wheel=0 stall too but
         * regressed wheel=265rpm convergence 1.1-1.4s -> 2.4-4.0s; with the
         * taper wheel=265/600rpm A/B showed no regression (1.18-1.44s). */
        .steer_friction_ff_current = 200.0f,
        /* Full breakaway assist at rest, linearly removed by 10 axis rpm.
         * A/B on 2026-07-31 cut wheel=0 mean settle 0.956->0.757s and
         * worst 2.040->0.975s without changing wheel>=30rpm behavior. */
        .steer_friction_ff_fade_axis_rpm = 10.0f,
        /* Kinetic-friction FF stays disabled (0); integral floor and motion
         * threshold are 2026-07-07 measured values (kinetic friction ~200 raw). */
        .drive_kinetic_ff_current = 0.0f,
        .drive_integral_floor_current = 200.0f,
        .drive_motion_threshold_rpm = 5.0f,
        /* 400: rides through local friction snags (breakaway up to ~950 raw)
         * while cutting the 850->200 breakaway kick; 250 re-sticks at snag
         * angles (2026-07-08 bench A/B, 25rpm 3/3 stuck-free). */
        .drive_onset_integral_clamp_current = 400.0f,
    };

    clock_init();
    board_io_init();
    debug_uart_init(115200U);
    bench_uart_init(115200U);
    amt22_init();
    unit_controller_init(&controller, &control_config);
    calibration_flash_init();

#if BENCH_SAVE_CURRENT_ZERO_ON_BOOT
    /* One-shot bench calibration image. The caller has positioned the lifted,
     * disabled unit at mechanical zero. Restore this macro to 0 immediately
     * after verifying the stored position. */
    clock_delay_ms(250U);
    amt22_sample_t zero_sample;
    const bool zero_read_ok = amt22_read(&zero_sample) &&
                              zero_sample.check_bits_ok;
    const bool zero_save_ok = zero_read_ok &&
                              calibration_flash_save_zero(zero_sample.position);
    debug_printf("ZERO_ON_BOOT raw=%u read=%u save=%u\n",
                 zero_read_ok ? (uint32_t)zero_sample.position : UINT32_MAX,
                 zero_read_ok ? 1U : 0U,
                 zero_save_ok ? 1U : 0U);
#endif

    const calibration_flash_status_t boot_calibration = calibration_flash_status();

    debug_printf("\n=== CAN target differential unit test ===\n");
    debug_printf("WHEEL MUST BE LIFTED CLEAR OF THE GROUND before UNIT_CTRL enable.\n");
    debug_printf("boots disabled; press B1 any time to abort and latch disabled\n");
    debug_printf("calibration: valid=%u zero=%u seq=%u crcErr=%u full=%u\n",
                 boot_calibration.calibrated ? 1U : 0U,
                 boot_calibration.calibrated
                     ? (uint32_t)boot_calibration.zero_position_counts : UINT32_MAX,
                 boot_calibration.sequence,
                 boot_calibration.crc_error ? 1U : 0U,
                 boot_calibration.page_full ? 1U : 0U);
    debug_printf("limit=%d iLimit=%d wheelAccel=%drpm/s targetTimeout=%ums\n",
                 (int32_t)control_config.current_limit,
                 (int32_t)control_config.mode_integral_limit,
                 (int32_t)control_config.wheel_accel_rpm_per_s,
                 TARGET_TIMEOUT_MS);
    clock_delay_ms(250U);

#if !BENCH_CONTROL_UART_ENABLED
    if (!fdcan_init(FDCAN_BUS_CENTRAL, FDCAN_MODE_NORMAL)) {
        debug_printf("FDCAN1 init FAILED\n");
        for (;;) {
            status_led_write(((clock_millis() / 100U) & 1U) != 0U);
        }
    }
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

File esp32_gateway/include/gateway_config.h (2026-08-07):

#pragma once

#ifndef DSD_UART_TX_GPIO
#define DSD_UART_TX_GPIO 17
#endif

#ifndef DSD_UART_RX_GPIO
#define DSD_UART_RX_GPIO 22
#endif

#ifndef DSD_UNIT_ID
#define DSD_UNIT_ID 1
#endif

#ifndef DSD_CONTROLLER_TIMEOUT_MS
#define DSD_CONTROLLER_TIMEOUT_MS 150
#endif

#ifndef DSD_UNIT_STATUS_TIMEOUT_MS
#define DSD_UNIT_STATUS_TIMEOUT_MS 250
#endif

#ifndef DSD_UART_PERIOD_MS
#define DSD_UART_PERIOD_MS 20
#endif

#ifndef DSD_TELEMETRY_PERIOD_MS
#define DSD_TELEMETRY_PERIOD_MS 50
#endif

#ifndef DSD_OFFLINE_LOG_FLUSH_PERIOD_MS
#define DSD_OFFLINE_LOG_FLUSH_PERIOD_MS 1000
#endif

#ifndef DSD_MAX_WHEEL_RPM
#define DSD_MAX_WHEEL_RPM 500.0f
#endif

#ifndef DSD_MIN_WHEEL_RPM_LIMIT
#define DSD_MIN_WHEEL_RPM_LIMIT 250.0f
#endif

#ifndef DSD_MAX_WHEEL_RPM_LIMIT
#define DSD_MAX_WHEEL_RPM_LIMIT 1300.0f
#endif

#ifndef DSD_WHEEL_RPM_LIMIT_STEP
#define DSD_WHEEL_RPM_LIMIT_STEP 250.0f
#endif

#ifndef DSD_MAX_STEER_DEG
#define DSD_MAX_STEER_DEG 90.0f
#endif

#ifndef DSD_STICK_DEADZONE
#define DSD_STICK_DEADZONE 0.10f
#endif

#ifndef DSD_STICK_LINEAR_MIX
#define DSD_STICK_LINEAR_MIX 0.35f
#endif

// Initial commissioning lock. Change to 1 only after Bluetooth input, UART
// CRC/status reception and lifted-wheel safety checks all pass.
#ifndef DSD_MOTOR_ENABLE_ALLOWED
#define DSD_MOTOR_ENABLE_ALLOWED 1
#endif

// One-shot commissioning option. Set back to 0 after a successful pairing so
// the controller can reconnect after reset.
#ifndef DSD_FORGET_BLUETOOTH_KEYS_ON_BOOT
#define DSD_FORGET_BLUETOOTH_KEYS_ON_BOOT 0
#endif

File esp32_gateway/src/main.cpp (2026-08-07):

#include <Arduino.h>
#include <Bluepad32.h>
#include <LittleFS.h>
#include <math.h>

#include "gateway_config.h"

namespace {

constexpr uint8_t kFrameSync0 = 0xa5u;
constexpr uint8_t kFrameSync1 = 0x5au;
constexpr uint8_t kFrameTypeCommand = 0x01u;
constexpr uint8_t kFrameTypeStatus = 0x81u;
constexpr size_t kFrameSize = 14u;
constexpr int32_t kFullTurnMdeg = 360000;
constexpr int32_t kMaxCommandAngleErrorMdeg = 90000;
constexpr char kOfflineLogPath[] = "/radio.csv";
constexpr char kTelemetryCsvHeader[] =
    "ms,bt,armed,enable,unit_active,target_steer_mdeg,actual_steer_mdeg,"
    "steer_error_mdeg,target_wheel_mrpm,actual_wheel_mrpm,wheel_error_mrpm,"
    "rpm_limit,controller_age_ms,unit_age_ms,uart_rx_frames,uart_rx_bad,"
    "uart_rx_gaps,uart_tx_fail\n";

ControllerPtr controller = nullptr;
HardwareSerial unit_uart(2);
bool have_controller_data = false;
bool have_unit_status = false;
bool armed = false;
bool enable_commanded = false;
bool unit_active = false;
bool previous_options = false;
bool previous_capture = false;
bool have_uart_rx_sequence = false;
bool littlefs_ready = false;
bool offline_log_active = false;
bool offline_log_dumping = false;
uint8_t previous_dpad = 0;
uint8_t last_uart_rx_sequence = 0;
uint32_t last_controller_data_ms = 0;
uint32_t last_unit_status_ms = 0;
uint32_t last_uart_ms = 0;
uint32_t uart_tx_failures = 0;
uint32_t uart_rx_frames = 0;
uint32_t uart_rx_bad_frames = 0;
uint32_t uart_rx_sequence_gaps = 0;
uint32_t offline_log_rows = 0;
uint32_t last_offline_log_flush_ms = 0;
uint8_t uart_tx_sequence = 0;
uint8_t uart_rx_buffer[kFrameSize] = {};
size_t uart_rx_count = 0;
int32_t current_steer_mdeg = 0;
int32_t current_wheel_rpm_milli = 0;
int32_t target_steer_mdeg = 0;
int32_t target_wheel_rpm_milli = 0;
float wheel_rpm_limit = DSD_MAX_WHEEL_RPM;
File offline_log_file;

float clampf(float value, float minimum, float maximum)
{
    if (value < minimum) {
        return minimum;
    }
    if (value > maximum) {
        return maximum;
    }
    return value;
}

int32_t wrap_angle_mdeg(int32_t angle)
{
    angle %= kFullTurnMdeg;
    return angle < 0 ? angle + kFullTurnMdeg : angle;
}

int32_t shortest_angle_error_mdeg(int32_t target, int32_t current)
{
    int32_t error = wrap_angle_mdeg(target) - wrap_angle_mdeg(current);
    if (error > kFullTurnMdeg / 2) {
        error -= kFullTurnMdeg;
    } else if (error < -kFullTurnMdeg / 2) {
        error += kFullTurnMdeg;
    }
    return error;
}

float normalize_axis(int32_t raw)
{
    return clampf(static_cast<float>(raw) / 512.0f, -1.0f, 1.0f);
}

float response_curve(float value)
{
    return DSD_STICK_LINEAR_MIX * value +
           (1.0f - DSD_STICK_LINEAR_MIX) * value * value * value;
}

float apply_axis_deadzone(float value)
{
    const float magnitude = fabsf(value);
    if (magnitude <= DSD_STICK_DEADZONE) {
        return 0.0f;
    }
    const float remapped =
        (magnitude - DSD_STICK_DEADZONE) / (1.0f - DSD_STICK_DEADZONE);
    return value < 0.0f ? -remapped : remapped;
}

void write_i32_le(uint8_t *destination, int32_t value)
{
    const uint32_t raw = static_cast<uint32_t>(value);
    destination[0] = static_cast<uint8_t>(raw & 0xffu);
    destination[1] = static_cast<uint8_t>((raw >> 8) & 0xffu);
    destination[2] = static_cast<uint8_t>((raw >> 16) & 0xffu);
    destination[3] = static_cast<uint8_t>((raw >> 24) & 0xffu);
}

int32_t read_i32_le(const uint8_t *source)
{
    const uint32_t raw = static_cast<uint32_t>(source[0]) |
                         (static_cast<uint32_t>(source[1]) << 8) |
                         (static_cast<uint32_t>(source[2]) << 16) |
                         (static_cast<uint32_t>(source[3]) << 24);
    return static_cast<int32_t>(raw);
}

uint8_t crc8(const uint8_t *data, size_t length)
{
    uint8_t crc = 0;
    for (size_t i = 0; i < length; ++i) {
        crc ^= data[i];
        for (uint8_t bit = 0; bit < 8; ++bit) {
            crc = (crc & 0x80u) != 0u
                      ? static_cast<uint8_t>((crc << 1u) ^ 0x07u)
                      : static_cast<uint8_t>(crc << 1u);
        }
    }
    return crc;
}

void send_uart_command(bool enable)
{
    uint8_t frame[kFrameSize] = {
        kFrameSync0, kFrameSync1, kFrameTypeCommand, uart_tx_sequence++,
    };
    write_i32_le(&frame[4], target_steer_mdeg);
    write_i32_le(&frame[8], target_wheel_rpm_milli);
    frame[12] = enable ? 1u : 0u;
    frame[13] = crc8(frame, kFrameSize - 1u);
    if (unit_uart.write(frame, sizeof(frame)) == sizeof(frame)) {
        enable_commanded = enable;
    } else {
        ++uart_tx_failures;
    }
}

void command_safe_stop()
{
    target_wheel_rpm_milli = 0;
    if (enable_commanded) {
        send_uart_command(false);
    }
}

void stop_offline_log(ControllerPtr ctl)
{
    if (!offline_log_active) {
        return;
    }
    offline_log_file.flush();
    offline_log_file.close();
    offline_log_active = false;
    Console.printf("offline-log: stopped rows=%lu path=%s\n",
                   static_cast<unsigned long>(offline_log_rows),
                   kOfflineLogPath);
    if (ctl != nullptr) {
        ctl->playDualRumble(0, 300, 60, 60);
    }
}

void start_offline_log(ControllerPtr ctl, uint32_t now_ms)
{
    if (!littlefs_ready) {
        Console.println("offline-log: LittleFS unavailable");
        if (ctl != nullptr) {
            ctl->playDualRumble(0, 500, 0, 150);
        }
        return;
    }
    LittleFS.remove(kOfflineLogPath);
    offline_log_file = LittleFS.open(kOfflineLogPath, FILE_WRITE);
    if (!offline_log_file) {
        Console.println("offline-log: open failed");
        if (ctl != nullptr) {
            ctl->playDualRumble(0, 500, 0, 150);
        }
        return;
    }
    offline_log_file.print(kTelemetryCsvHeader);
    offline_log_rows = 0;
    last_offline_log_flush_ms = now_ms;
    offline_log_active = true;
    Console.printf("offline-log: started path=%s\n", kOfflineLogPath);
    if (ctl != nullptr) {
        ctl->playDualRumble(0, 120, 40, 40);
    }
}

void dump_offline_log(ControllerPtr ctl)
{
    if (!littlefs_ready || offline_log_active) {
        Console.println("offline-log: dump unavailable while recording");
        return;
    }
    File source = LittleFS.open(kOfflineLogPath, FILE_READ);
    if (!source) {
        Console.println("offline-log: no saved log");
        if (ctl != nullptr) {
            ctl->playDualRumble(0, 500, 0, 150);
        }
        return;
    }
    offline_log_dumping = true;
    Console.println("OFFLINE_LOG_BEGIN");
    while (source.available() > 0) {
        Console.write(static_cast<char>(source.read()));
    }
    Console.println("OFFLINE_LOG_END");
    source.close();
    offline_log_dumping = false;
    if (ctl != nullptr) {
        ctl->playDualRumble(0, 200, 30, 30);
    }
}
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

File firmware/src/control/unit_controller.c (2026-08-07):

#include "control/unit_controller.h"

enum {
    /* Per-motor gear train 40:55:60:15. Drive path goes through both stages:
     * mode * (40/55)*(60/15) = 32/11. Steer path only reaches the 40:55
     * stage (the 60:15 bevel is after the differential): mode * 40/55 = 8/11.
     * The old 2/11 wrongly included the 60/15 stage; bench-verified 2026-07-08
     * (AMT axis rate 30deg/s vs motor-derived rate matched 8/11 within 0.4%). */
    DRIVE_RATIO_NUM = 32,
    DRIVE_RATIO_DEN = 11,
    STEER_RATIO_NUM = 8,
    STEER_RATIO_DEN = 11,
    WHEEL_LOW_SPEED_TRANSITION_RPM = 30,
};

static float absf(float value)
{
    return value < 0.0f ? -value : value;
}

static float clampf(float value, float minimum, float maximum)
{
    if (value < minimum) {
        return minimum;
    }
    if (value > maximum) {
        return maximum;
    }
    return value;
}

static const float steer_gain_knot_speeds_rpm[UNIT_STEER_GAIN_KNOT_COUNT] = {
    0.0f, 60.0f, 100.0f, 150.0f,
};

static float lerpf(float lower, float upper, float fraction)
{
    return lower + (upper - lower) * fraction;
}

static void interpolate_steer_gain_schedule(
    const unit_controller_t *controller, float schedule_rpm,
    unit_steer_gain_knot_t *scheduled)
{
    if (schedule_rpm <= controller->steer_gain_knots[0].speed_rpm) {
        const unit_steer_gain_knot_t *knot = &controller->steer_gain_knots[0];
        scheduled->speed_rpm = schedule_rpm;
        scheduled->mode_kp = knot->mode_kp;
        scheduled->mode_ki = knot->mode_ki;
        scheduled->accel_ff_gain = knot->accel_ff_gain;
        scheduled->decel_ff_gain = knot->decel_ff_gain;
        scheduled->backcalc_gain = knot->backcalc_gain;
        scheduled->brake_kp_multiplier = knot->brake_kp_multiplier;
        return;
    }
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

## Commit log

2026-04-28 Add CAD files (ver1-ver4), docs, and .gitignore
    [1.75 25T pinion(below).SLDPRT, 1.75 25T pinion.SLDPRT, 15T straight bevel pinion.SLDPRT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]
2026-07-06 Add control firmware, architecture docs, and current CAD
    Capture the tested STM32 control stack, coordinated-control decisions, hardware references, and latest mechanical design assets so development can continue from a shared baseline.
    [10×15 角パイプ穴あけガイド.SLDASM, 16.SLDPRT, 17.SLDPRT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]
2026-07-06 Document completed wheel-step test
    Record removal of the redundant rpm guard, the successful ten-second run, and the observed steering coupling so the next tuning session starts from the measured result.
2026-07-07 Add runtime SET_CONFIG and friction compensation for low-rpm stick-slip
    - SET_CONFIG (0x140+unitId) tunes 17 control params live over CAN
    - Identify kinetic friction at ~200 raw (speed-independent, symmetric)
    via steady-state iDrive at 75-500 rpm both directions
    - Add drive integral floor, kinetic FF, and onset integral clamp;
    bench A/B selected floor=200 + driveKp=10 + onset clamp=400
    (40rpm p-p 213->16, 25rpm stuck 46%->0%), baked into defaults
    - Add tools/linux/unit_bench.py (socketcan bench CLI) and switch
    flash.sh to st-flash for the Linux mini PC
    [main.c, unit_controller.c]
2026-07-07 Raise response bandwidth: wheel accel 4000, drive Kp 30, current limit 4000
    - Identify limiter chain: target ramp (200rpm/s placeholder) -> drive PI
    bandwidth -> current limit; tune each via SET_CONFIG A/B on the bench
    - 0->500rpm rise 2.5s -> 0.41s, full +-500 reversal 5.2s -> 0.51s,
    overshoot 15% -> 4.2%; 25rpm low-speed also improves (p-p 7.1, no stick)
    - Raise current_limit ceiling 2000 -> 6000 (user-approved) and wheel accel
    ceiling to 5000; bake defaults cl=4000/accel=4000/Kp=30, steer 10rpm/150
    - Document disable-coast coupling (wheel inertia swings steer up to 43deg
    on disable at speed): always ramp wheel to 0 before disabling
    - Profile/step/reversal test logs from the tuning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
    [profile-reversal-fast.csv, profile-reversal-v1.csv, steer-fast-test.csv]
2026-07-07 Add SET_TARGET_FF steer-rate feedforward; fix 4x STEER_RATIO error
    - Implement SET_TARGET_FF (0x110+unitId) per spec: steer rate FF added to
    the angle-P output, 200ms staleness fallback to 0, ffS= telemetry;
    wheel-accel FF parsed and logged for future use
    - unit_bench.py: run --steer-rate-dps for combined theta_s/omega_s/omega_w
    commands, optional steer_rate_mdeg_s CSV column in profile
    - FF testing exposed a 4.00x kinematics bug: the 60:15 bevel stage only
    exists in the drive path after the differential, but docs/firmware
    included it in the steer path too. STEER_RATIO corrected 2/11 -> 8/11
    (measured 0.3623 vs theoretical 0.3636); outer steer params rescaled x4
    (angle_kp 2.0,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
    [rot30-noff-w0.csv, rot30-noff.csv]
2026-07-07 Add browser test UI for steer angle/rate and wheel rpm commands
    - tools/linux/unit_web_ui.py: single-file stdlib HTTP server + dark page
    with theta_s/omega_w/omega_s sliders, enable/STOP/disable, live telemetry
    - Safety verified on hardware: steer target seeded from current angle with
    a fresh SET_TARGET landed before enable (stale-target divergence trip
    found in testing), STOP ramps wheel to 0 for 1s before disable, dead-man
    auto-stop after 3s without browser polls, disable on exit
    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
2026-07-07 Web UI: leash target to measured angle, omega_s as approach speed to theta_s
    - Target leash (+45deg past measured angle) prevents the 120deg divergence
    latch when commands exceed the shared motor-speed envelope; live display
    of available omega_s/omega_w at the current setpoints
    - omega_s semantics changed per request: approach speed toward the theta_s
    destination with FF sent only while moving, then hold at the target
    (0 = instant step as before); verified +90deg at 30deg/s then hold <0.5deg
    - Firmware idle line now reports fdbkOk/en/tgtOk; UI surfaces missing C620
    feedback (24V power off) which silently blocks enable
    - Fix /api/set ordering so a rate sent together with the angle i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
    [main.c]
2026-07-14 Update project files
    [Anguler pipe 10×15 205.5mm.SLDPRT, 15T straight bevel pinion2.SLDPRT, 16.SLDPRT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]
2026-07-17 docs: refine board architecture and wiring
2026-07-19 Add KiCad part library (SamacSys-based) and part selection docs
    - hardware/lib: TCAN1051VDRQ1/ESD2CAN24DBZRQ1/LM66100DCKR/JS102011SAQN
    symbols imported from Component Search Engine with fixes
    (TCAN pin5 NC->VIO, ERC pin types, footprint refs), Harwin S1751-46R
    and JS102011SAQN footprints, library manifest and lib-table templates
    - docs/electrical: CAN/5V/G474 minimum-circuit part selection,
    schematic design open items; update board requirement docs
    - hardware/reference/datasheets: TI TCAN1051/ESD2CAN24/LM66100,
    Harwin S1751R
    - hardware/unit-board: empty KiCad 10 project skeleton
    - .gitignore: ignore KiCad auto-generated files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
    [unit-board.kicad_pcb, unit-board.kicad_sch]
2026-07-19 Update CAD files and add sensor module, E-stop, lipo parts
    [Anguler pipe 10×15 205.5mm.SLDPRT, 15T straight bevel pinion2.SLDPRT, 16.SLDPRT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]
2026-07-20 docs: add electrical schematics and pin assignments
2026-07-22 Add unit board schematic blocks
    [5V monitoring.kicad_sch, STM32G474 Minimum System.kicad_sch, amt22_spi.kicad_sch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]
2026-07-22 Record next PCB design phase
2026-07-22 Record unit board schematic audit progress
2026-07-23 fix(hardware): resolve unit board ERC violations
    [5V monitoring.kicad_sch, STM32G474 Minimum System.kicad_sch, can_main_interface.kicad_sch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]
2026-07-23 chore(hardware): update unit board design
    [STM32G474 Minimum System.kicad_sch, can_interface.kicad_sch, can_main_interface.kicad_sch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]
2026-07-24 chore: update CAD and finalize unit board layout
    [.step, 26_ASM.SLDASM, 2_ASM.SLDASM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]
2026-07-24 Untrack third-party vendor CAD downloads and installer binaries
    GrabCAD/PARTcommunity/manufacturer CAD models (RoboMaster, Hokuyo
    UTM-30LX, AMT102 encoder, HAMMER_CASTER caster, omni wheel, LM5UU
    bearing, XT30 connector) and Hokuyo's UrgBenriPlus/UtmUpdater
    installers were committed as-is; their source terms of use generally
    restrict redistribution. Add them to .gitignore and drop from the
    index so the repo can safely go public. History still contains them
    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
    [420G-R 38.sldasm, 420G-R 38p.sldprt, 425G-R 38.sldprt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]
2026-07-25 Resolve odometry board ERC and finalize unit board CAD outputs
    - AMT102 encoder input buffers: consolidate the per-channel 74LVC2G17
    from 2 parts (one gate each, power unit unplaced) into 1 part using
    all 3 units (gate A + gate B + power), wired to GND/PWR_3.3V. Fixes
    the remaining 18 ERC violations; odometry board schematic is now
    0 errors / 0 warnings across all sheets.
    - Add odometry board schematic reference doc, block-diagram figures,
    and schematic+BOM HTML/PDF exports.
    - Add DifferentialSwerve logo library (footprint + symbol) referenced
    by the schematics.
    - Finalize unit board layout/CAD and commit fabrication outputs
    (Gerbers, drill report, JLCPCB BOM, STEP model).
    - Ig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
    [AMT102_input.kicad_sch, CAN_interface.kicad_sch, Oddom board.kicad_pcb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]
2026-07-26 WIP: place odometry board footprints
    [AMT102_input.kicad_sch, CAN_interface.kicad_sch, Oddom board.kicad_pcb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]
2026-07-28 WIP: route odometry board RevA
    [AMT102_input.kicad_sch, CAN_interface.kicad_sch, Oddom board.kicad_pcb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]
2026-07-29 Finalize odometry board silkscreen and fabrication outputs
    [Oddom board-B_Cu.gbl, Oddom board-B_Mask.gbs, Oddom board-B_Paste.gbp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]
2026-07-30 feat: add profiled swerve control and realtime vector UI
    [samples.csv, summary.csv, trials.csv]
2026-07-31 docs: plan high-response steering control and CAN FD
2026-08-07 docs: save central board design and RC drive milestone
    [100-power.kicad_sch, 100-power.sch, 200-teensy.kicad_sch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]
2026-08-07 feat: save steering control and radio bench progress
2026-09-26 Update project design and manufacturing artifacts
    [Anguler pipe 10×15 205.5mm.SLDPRT, .step, .step.SLDASM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]
2026-09-30 Save all current circuit, firmware, CAD and manufacturing work
    [5V monitoring.kicad_sch, CAN1-1.kicad_sch, CAN2-1.kicad_sch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]
2026-09-30 Select X402 ground net tie and save central board updates
    [central-board.kicad_pcb, safety-1.kicad_sch]
2026-10-20 Update mechanical CAD assemblies and parts
